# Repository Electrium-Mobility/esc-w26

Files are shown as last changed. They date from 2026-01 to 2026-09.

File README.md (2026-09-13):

# Electrium Mobility 2026 ESC
This repository contains all the firmware and hardware for Electrium Mobility's 2026 ESC, which is a 36V/15A 3-phase BLDC motor controller built around the STSPIN32G4 SiP's integrated gate driver and STM32G4 MCU, supporting 6-step and FOC commutation!

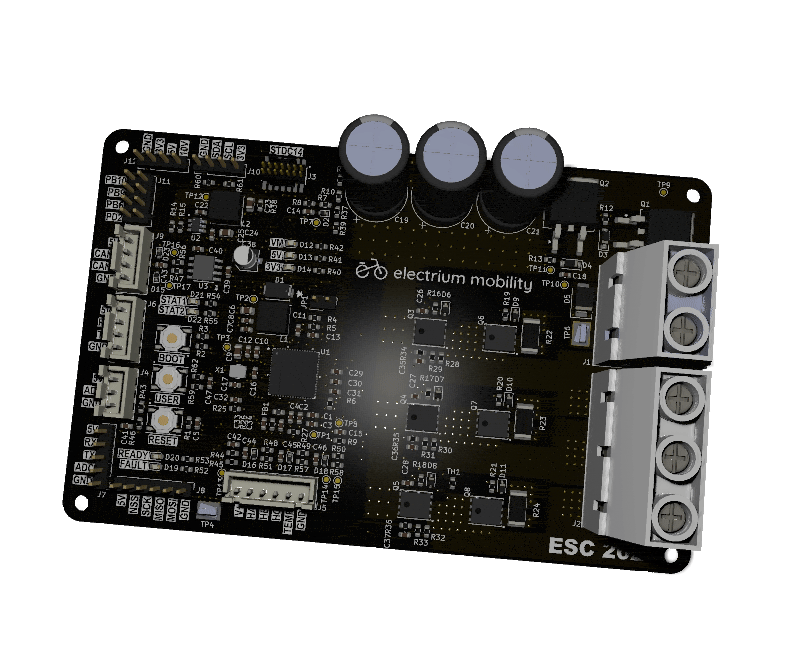
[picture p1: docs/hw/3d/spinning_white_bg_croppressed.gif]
 

## Architecture
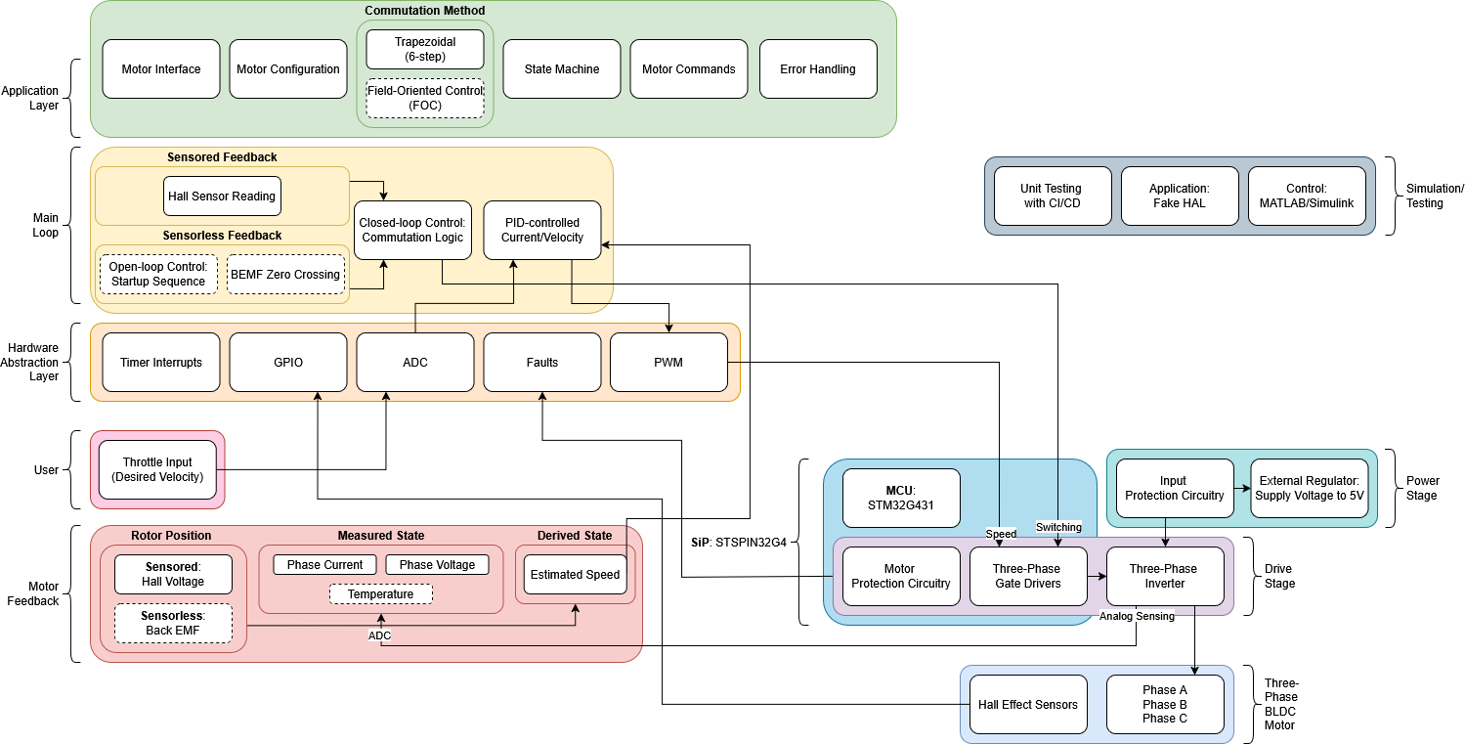
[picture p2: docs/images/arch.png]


## Features

### Power
- **Voltage**: 10-36V (maximum 10S battery pack)
- **Current**: 15A continuous (25A peak)
- **Power**: 500W (implied by above)
- External 5V/1A Buck Regulator
- Internal VCC (using 10V)/200mA Buck Regulator
- Internal 3.3V/150mA LDO
- 1410uF Bulk Capacitor Bank (bleed resistor discharges it in 1 min)

### Input Protection
- Reverse Polarity Protection (dual back-to-back PMOS)
- Inrush Current Limiting (RC soft-start)
- Transient Overvoltage Protection (60V TVS clamp)
- Short-circuit and Overcurrent Protection (SCREF divider)

### Sensing
- Phase Currents (0.5m shunt resistors) using Internal PGA with Overcurrent Protection (note: measures negative currents, but regenerative braking is not supported)
- Phase Voltages (for sensorless feedback method using BEMF zero-crossings)
- PCB Temperature (NTC thermistor)

### Interfaces
- Power Supply Input (VM+, VM-)
- SWD Programming/Debug (STDC14)
- **Throttle**: UART (digital commands), ADC (analog pot)
- **Motor**: Phase Outputs (U, V, W), Hall Sensors (A, B, C), Winding Temperature
- CAN (FD)
- Expansion Headers: SPI, I2C, 4 unused pins

### User I/O
- **Buttons**: RESET, BOOT, USER
- **LEDs**: Power Rails, READY, FAULT, 2 configurable (STATUS1, STATUS2)
- Onboard Test Points

### Board 
- 4-layer (stackup: Signal/Power, Ground, Ground, Signal)
- 125x80mm with 2oz Outer and 0.5oz Inner Copper
- Partitioned Grounding Scheme (separates high-power PGND and logic GND)

## Schematic
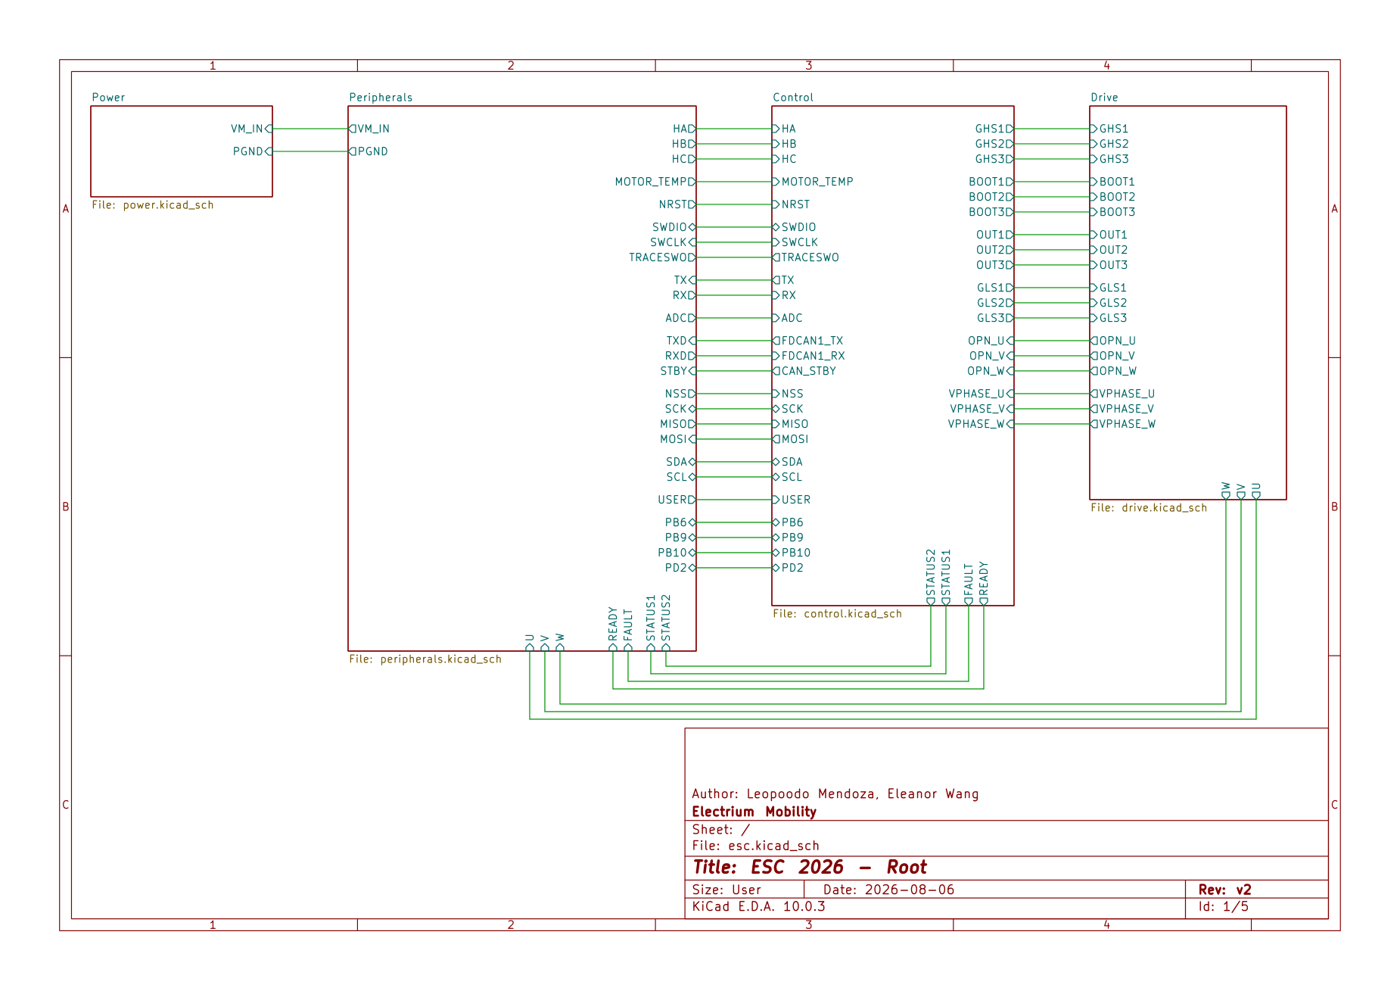
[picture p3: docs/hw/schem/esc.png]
 

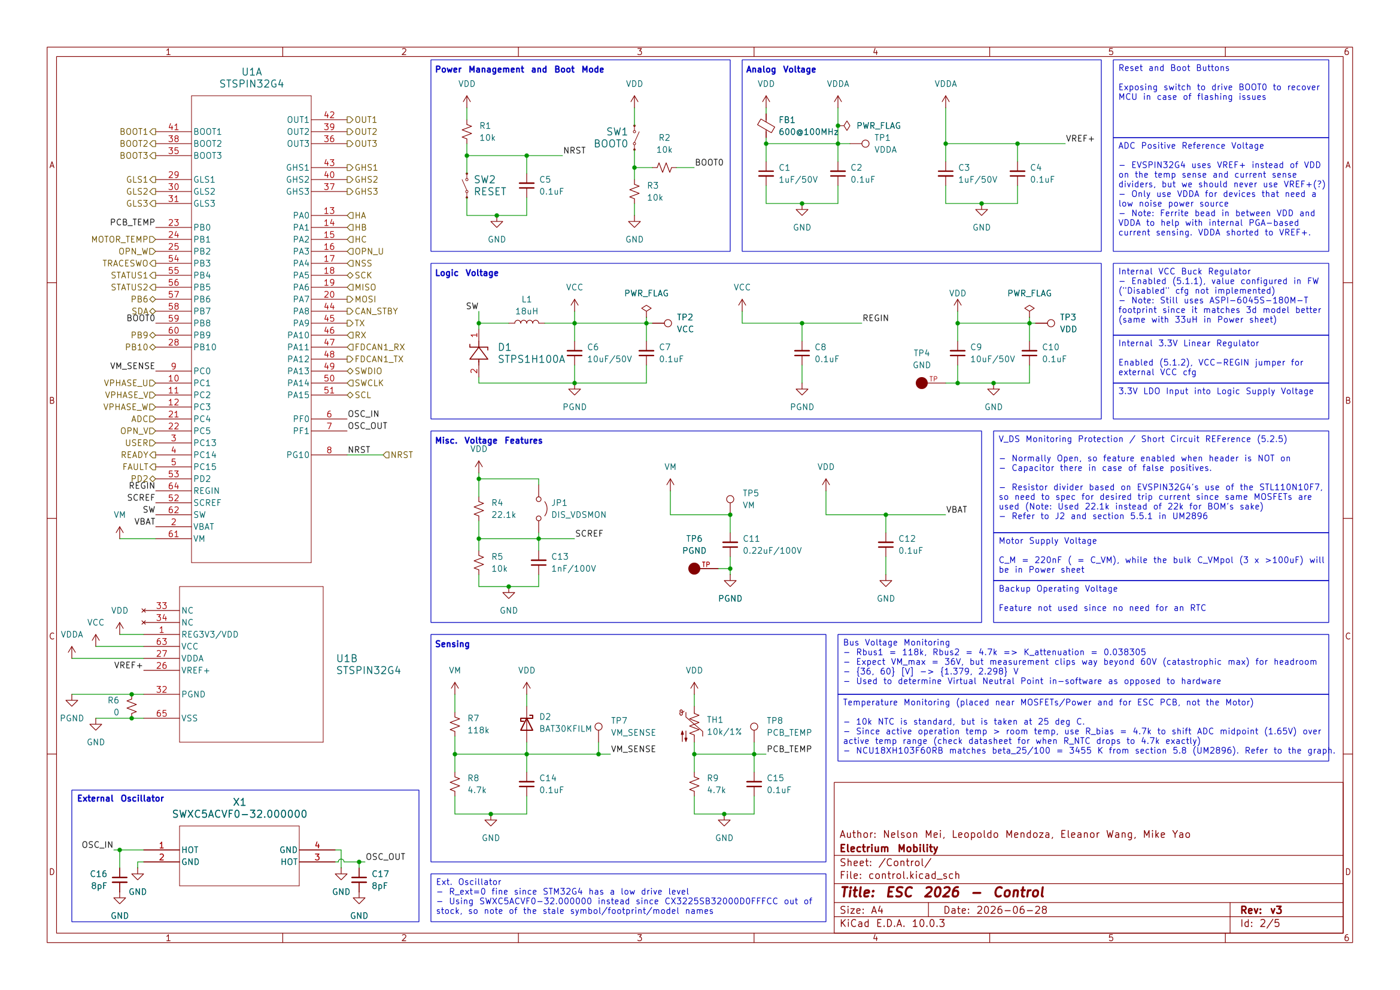
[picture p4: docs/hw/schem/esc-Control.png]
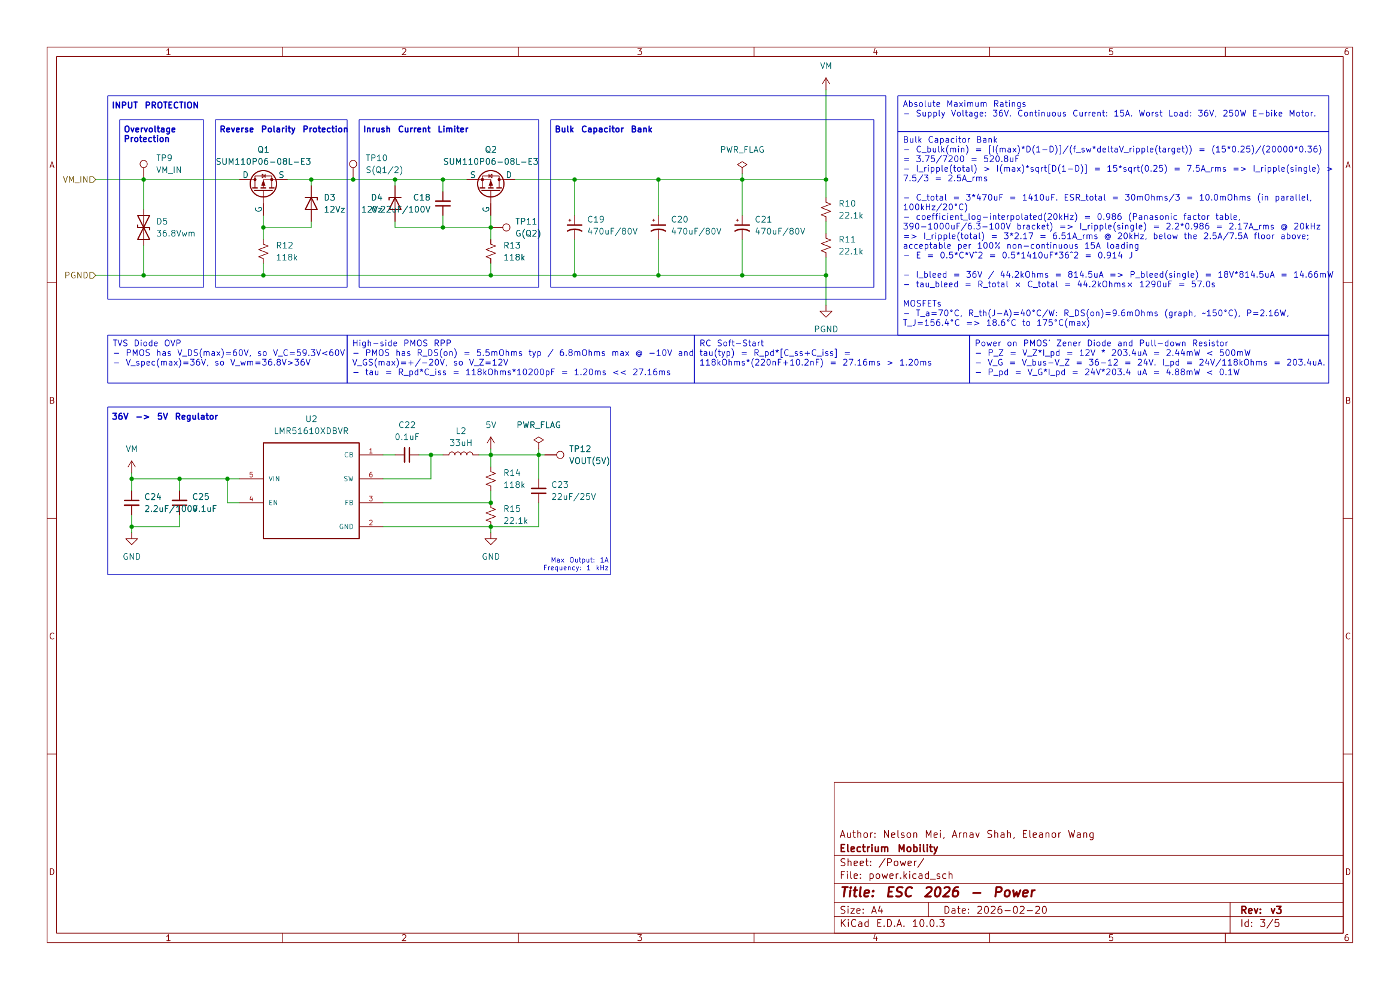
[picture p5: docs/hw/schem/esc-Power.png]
  
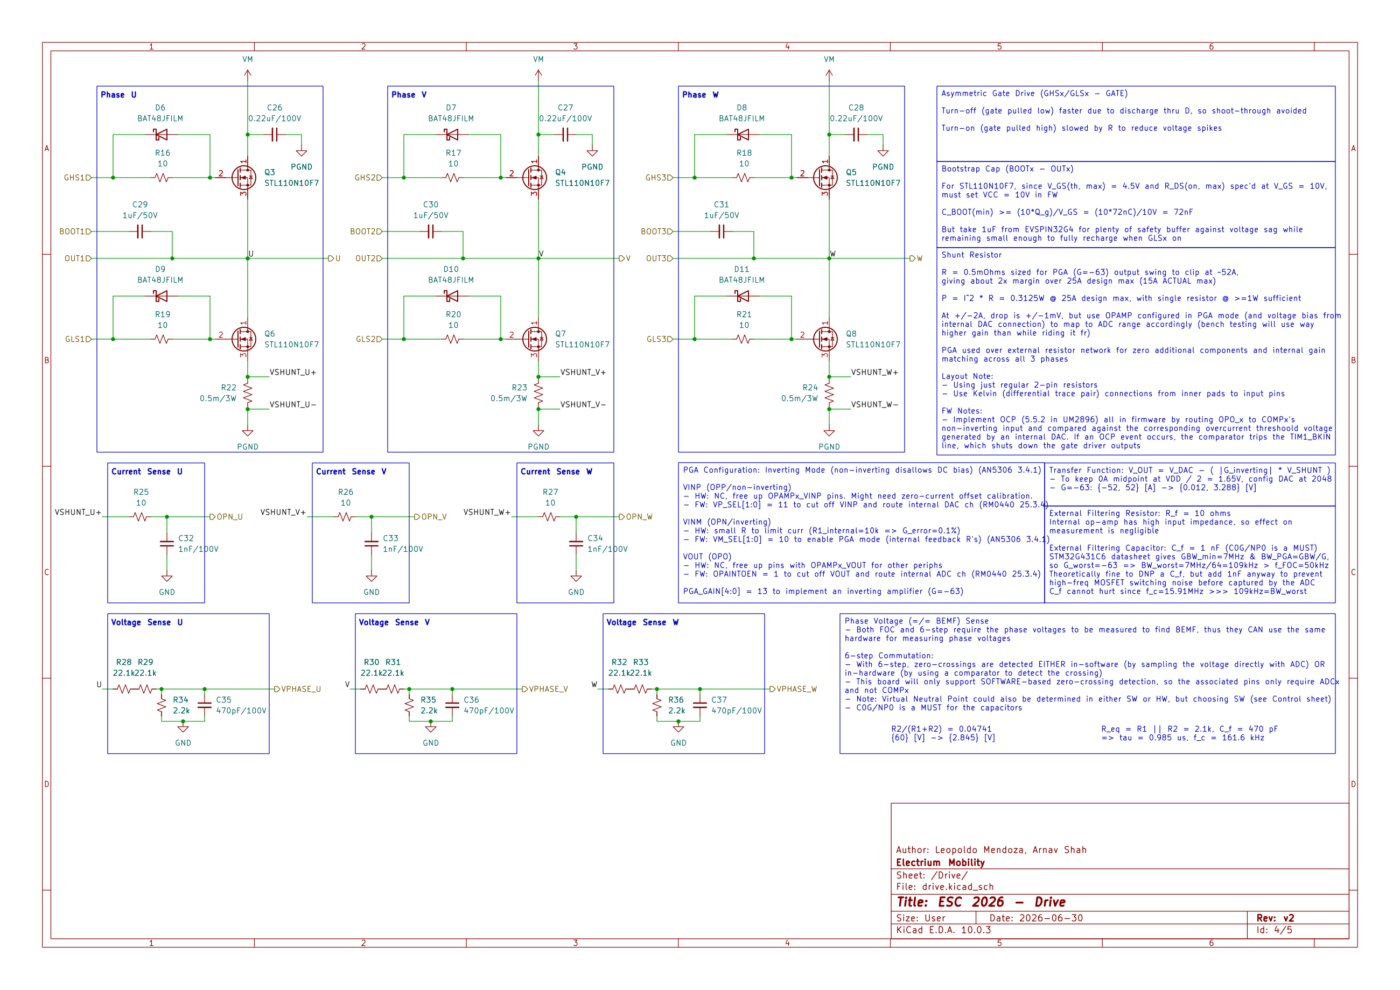
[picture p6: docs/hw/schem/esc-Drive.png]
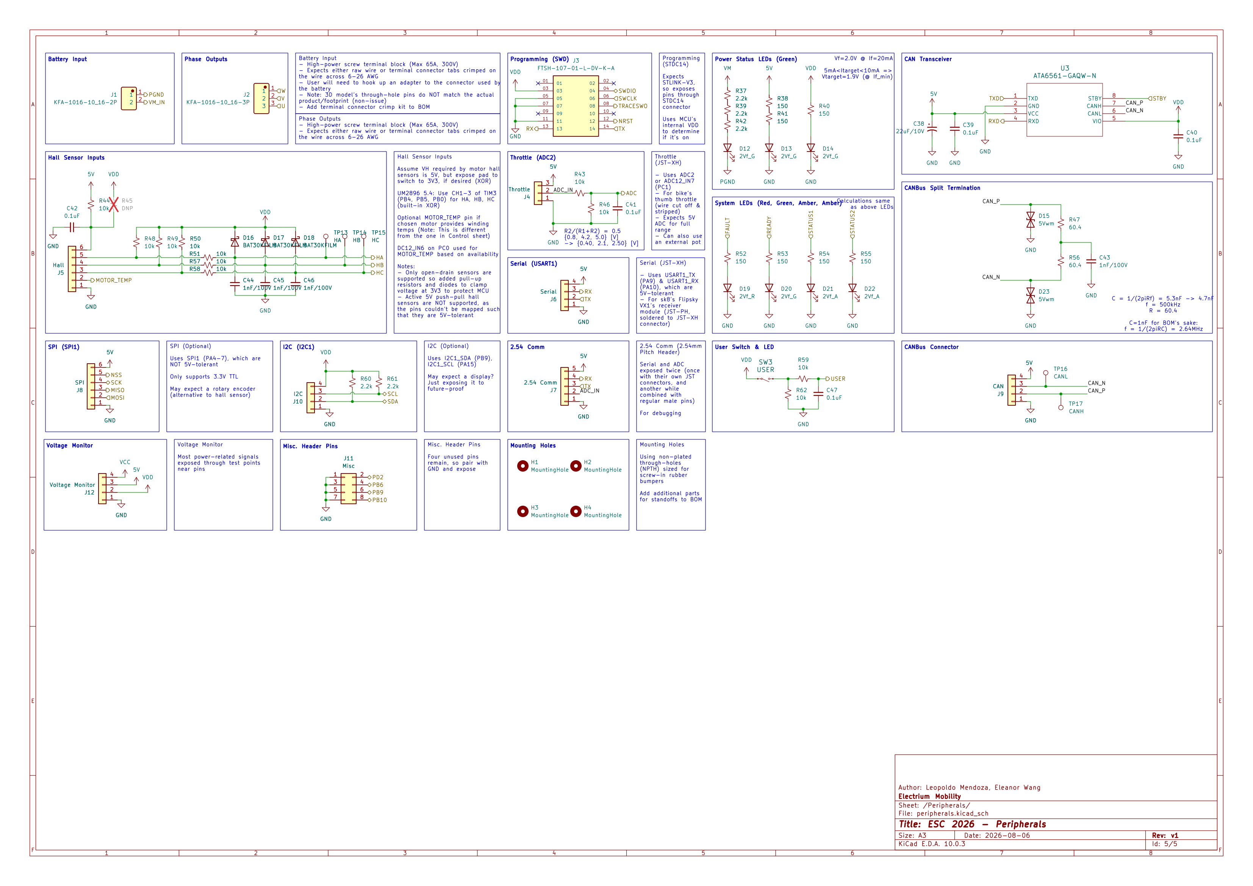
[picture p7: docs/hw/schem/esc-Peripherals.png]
  

## Routing

### Coloured (Traces Only, With Zones and Silkscreen)
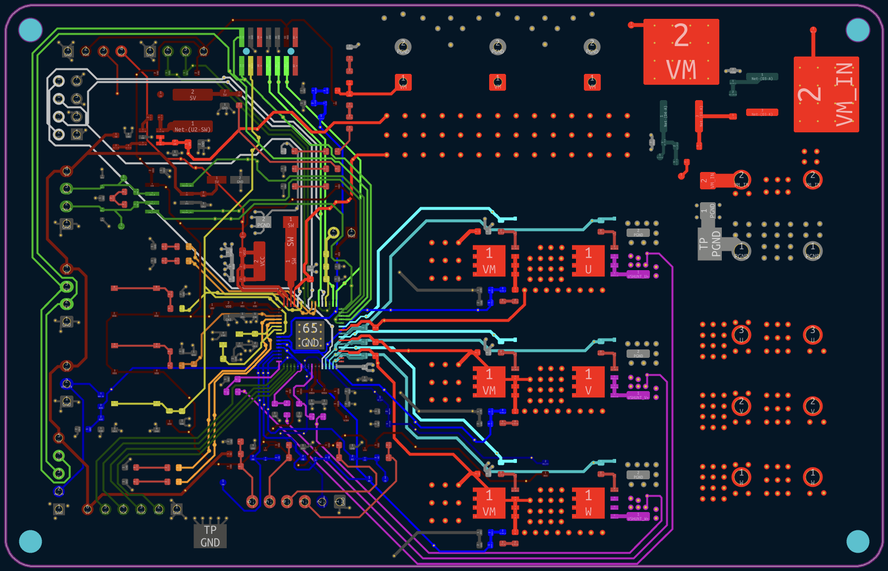
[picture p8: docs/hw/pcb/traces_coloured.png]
 
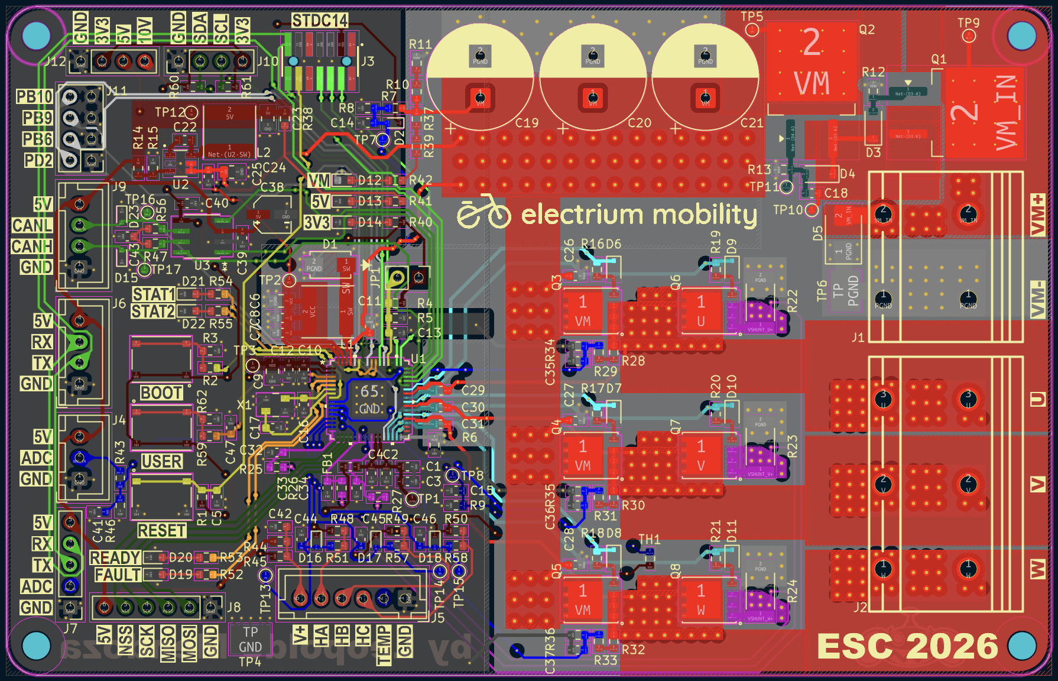
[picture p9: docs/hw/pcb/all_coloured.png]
 

### Colourless (Traces Only, With Zones and Silkscreen)
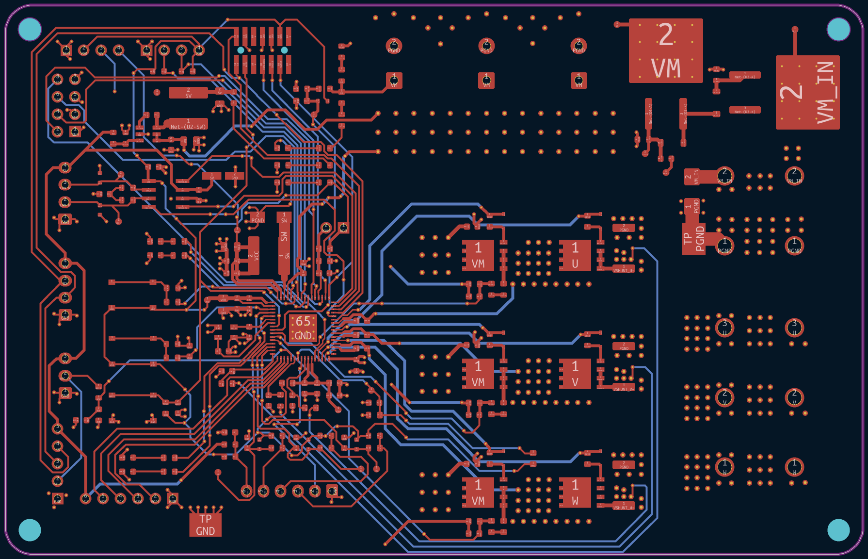
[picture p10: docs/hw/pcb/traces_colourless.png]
 
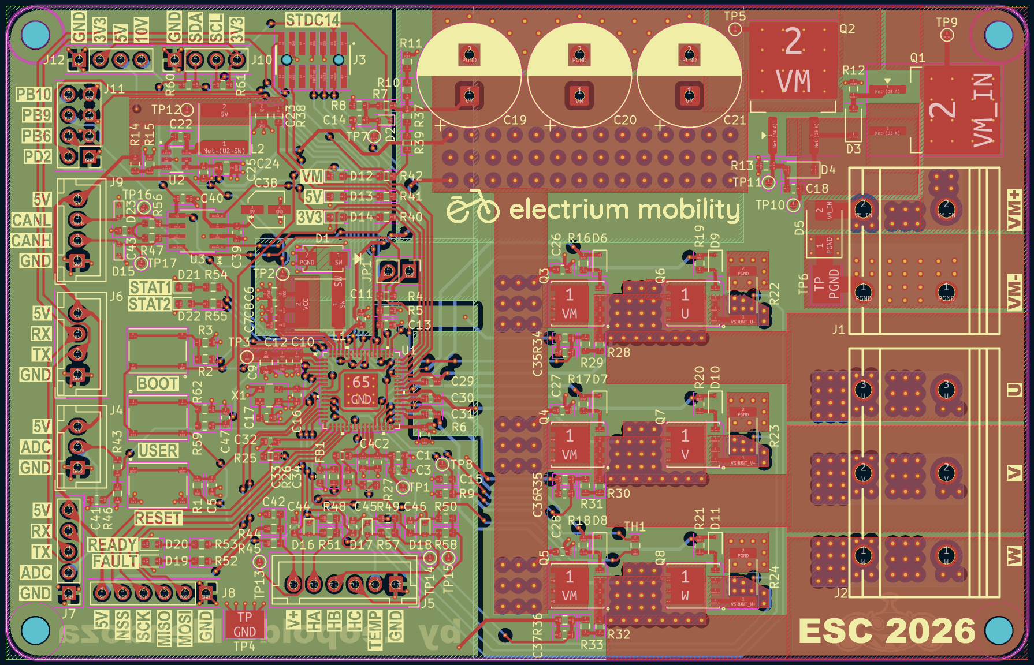
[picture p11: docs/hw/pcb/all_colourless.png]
 

## 3D Renders
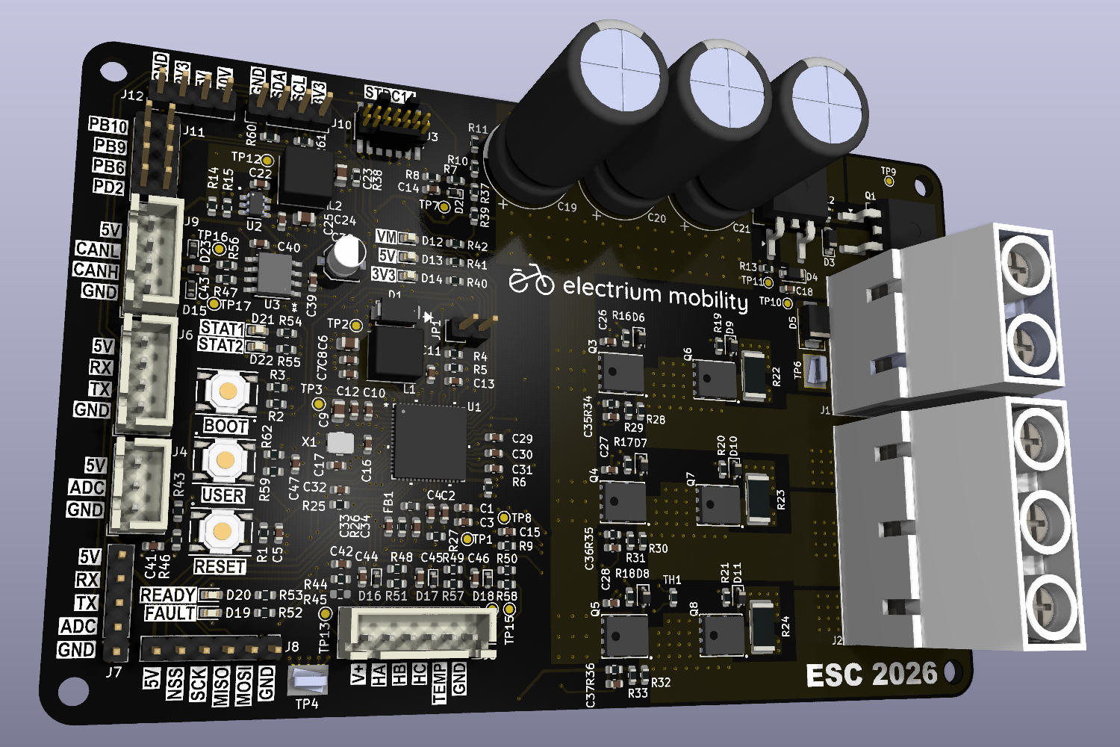
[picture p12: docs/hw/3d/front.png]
 
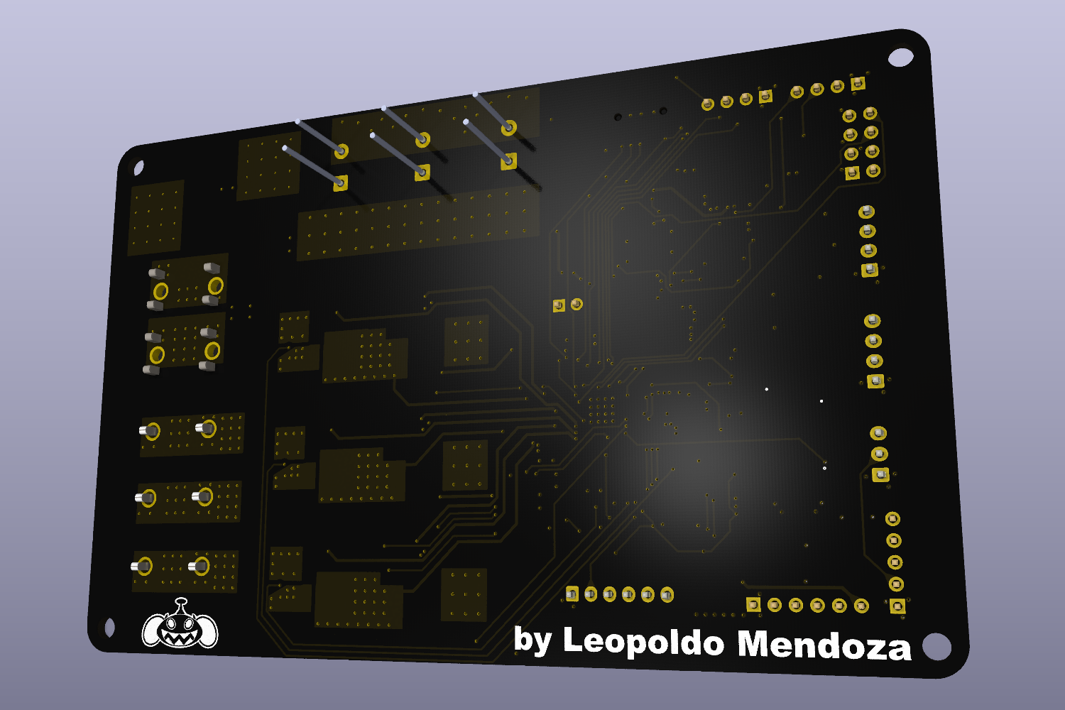
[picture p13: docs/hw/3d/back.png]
 

## Assembled Board
⚠️Under Construction⚠️

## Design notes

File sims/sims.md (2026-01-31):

This is where MATLAB and Simulink stuff will live.
For future reference, note that simulation (using close-to motor data) will happen on MATLAB/Simulink. 
This is in contrast to simple unit testing (not tryna model the system, but just if the application works as intended, with the the fake plaftorm functions subbed in for the real STM32 HAL functions), which will happen in the tests/ folder using the fake HAL implementations in platform/host/src/

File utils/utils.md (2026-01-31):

Math stuff like PID and filters will live here

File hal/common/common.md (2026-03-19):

This will contain the wrapper for the HAL called on by the application layer of the project!
Thus, depending on the target device (either a host PC or STM32 microcontroller), we configure the header files in /hal/common/inc/ to USE the corresponding implementation (in either /hal/host/src/ OR /hal/stm32/src/) under the hood.

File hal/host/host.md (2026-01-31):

This is where the "fake" implementation of the HAL wrapper functions will live. 
Before flashing the project onto an STM32 (and thus using the STM32 HAL under the hood of the HAL wrappers) to test with real hardware, we must simulate the HAL on a host PC.

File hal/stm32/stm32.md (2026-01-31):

All the junk (not actually, they're quite important auto-generated files) that the STM32CubeIDE will eventually go here (when we get there)

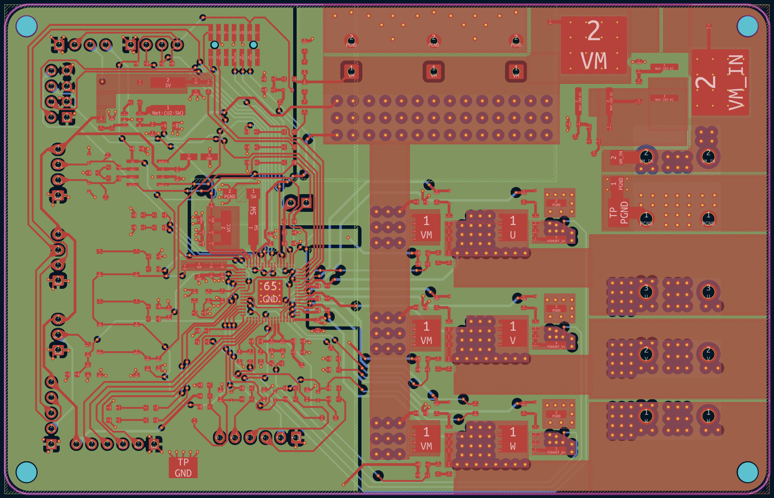
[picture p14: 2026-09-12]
docs/hw/pcb/traces_zones_colourless.png

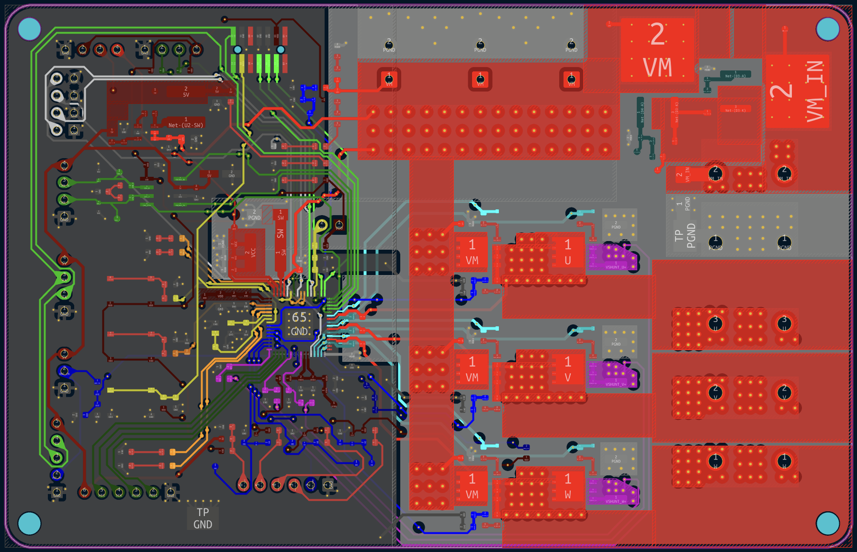
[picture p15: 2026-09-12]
docs/hw/pcb/traces_zones_coloured.png

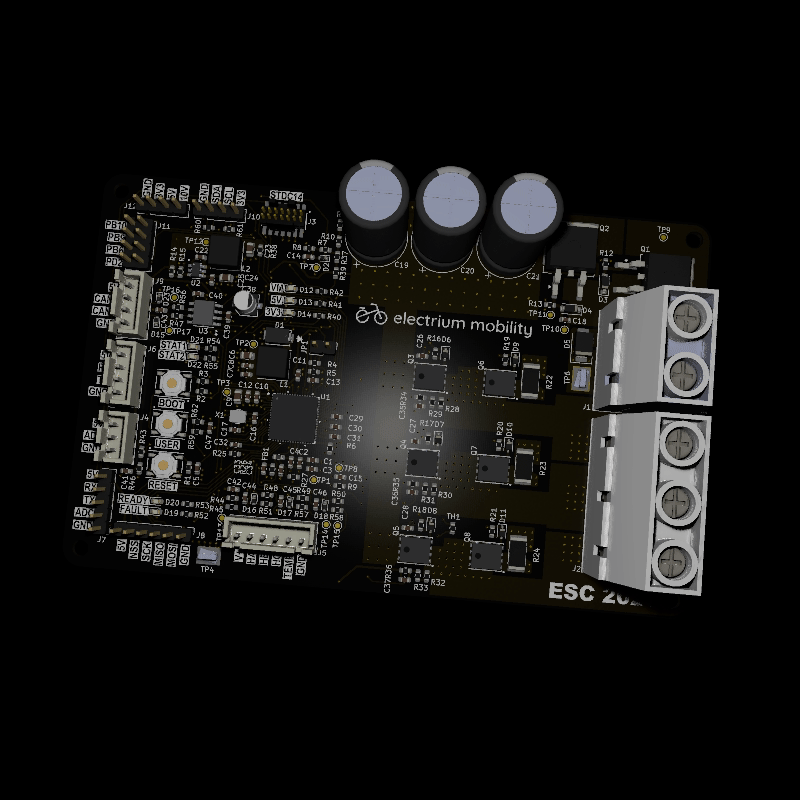
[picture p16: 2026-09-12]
docs/hw/3d/spinning_black_bg.gif

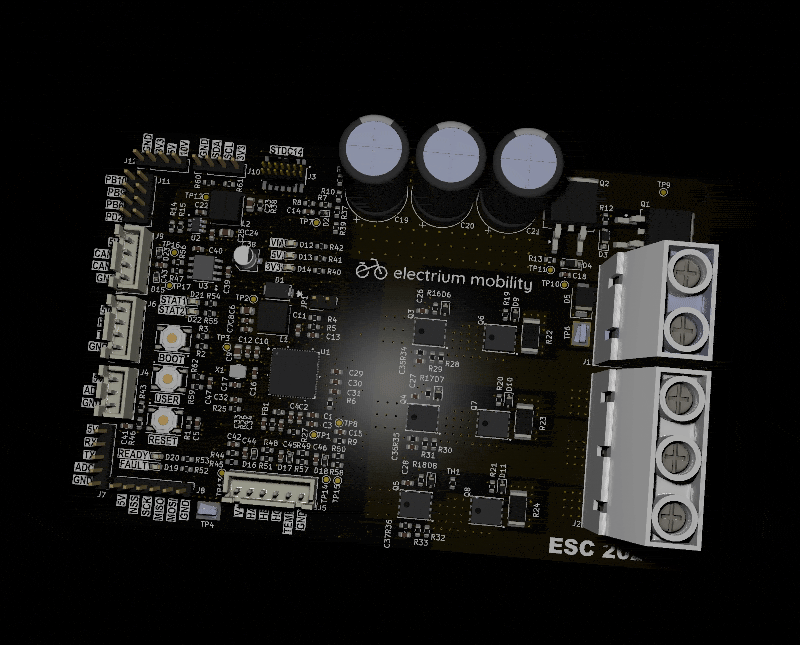
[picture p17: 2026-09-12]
docs/hw/3d/spinning_black_bg_croppressed.gif

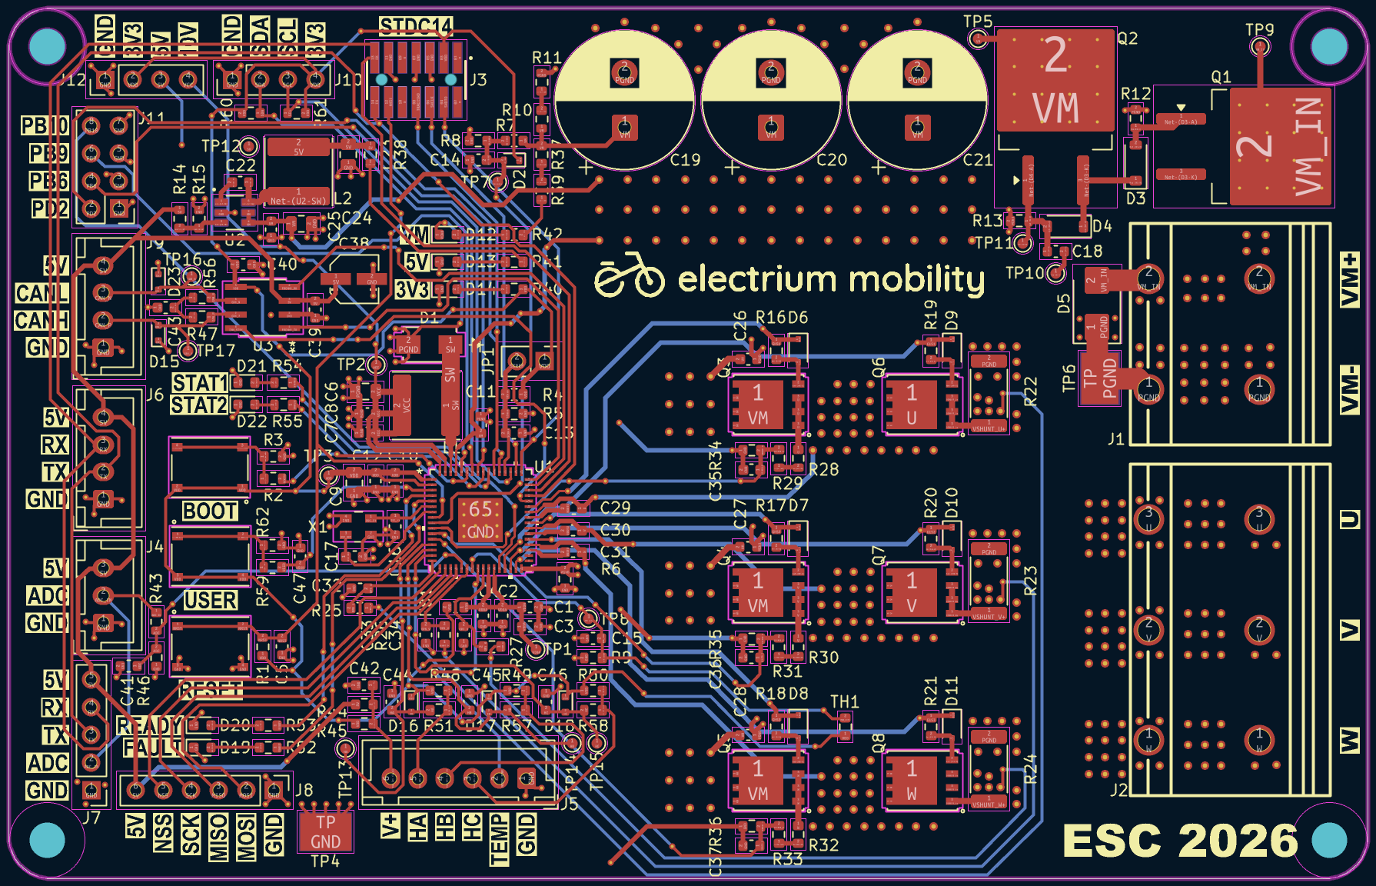
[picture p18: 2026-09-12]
docs/hw/pcb/traces_silk_colourless.png

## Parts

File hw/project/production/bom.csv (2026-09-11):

Designator | Footprint | Quantity | Value | LCSC Part #
C1, C29, C3, C30, C31 | 0603 | 5 | 1uF/50V | C15849
C10, C12, C14, C15, C2, C22, C25, C39, C4, C40, C41, C42, C47, C5, C7, C8 | 0603 | 16 | 0.1uF | C15725
C11, C18, C26, C27, C28 | 0603 | 5 | 0.22uF/100V | C2169715
C13, C32, C33, C34, C43, C44, C45, C46 | 0603 | 8 | 1nF/100V | C113793
C16, C17 | 0603 | 2 | 8pF | C519117
C19, C20, C21 | CP_Radial_D12.5mm_P5.00mm | 3 | 470uF/80V | C385881
C23 | 0805 | 1 | 22uF/25V | C45783
C24 | 0805 | 1 | 2.2uF/100V | C2981733
C35, C36, C37 | 0603 | 3 | 470pF/100V | C326973
C38 | EEEFKC220UAR | 1 | 22uF/10V | C401733
C6, C9 | 0805 | 2 | 10uF/50V | C440198
D1 | SMA_STM | 1 | STPS1H100A | C165701
D10, D11, D6, D7, D8, D9 | D_SOD-323 | 6 | BAT48JFILM | C2798199
D12, D13, D14, D20 | 0603 | 4 | 2Vf_G | C125098
D15, D23 | D_SOD-523 | 2 | 5Vwm | C51912417
D16, D17, D18, D2 | D_SOD-523 | 4 | BAT30KFILM | C2926449
D19 | 0603 | 1 | 2Vf_R | C94869
D21, D22 | 0603 | 2 | 2Vf_A | C5730905
D3, D4 | D_SOD-123 | 2 | 12Vz | C699126
D5 | D_SMB | 1 | 36.8Vwm | C468909
FB1 | 0603 | 1 | 600@100MHz | C304319
J1 | KFA-1016-10_16-2P | 1 | KFA-1016-10_16-2P | C475110
J10 | PinHeader_1x04_P2.54mm_Vertical | 1 | I2C | C3329732
J11 | PinHeader_2x04_P2.54mm_Vertical | 1 | Misc | C3333874
J12 | PinHeader_1x04_P2.54mm_Vertical | 1 | Voltage Monitor | C3329732
J2 | KFA-1016-10_16-3P | 1 | KFA-1016-10_16-3P | C475111
J3 | SAMTEC_FTSH-107-01-L-DV-K-A | 1 | FTSH-107-01-L-DV-K-A | C5563894
J4 | JST_XH_B3B-XH-A_1x03_P2.50mm_Vertical | 1 | Throttle | C144394
J5 | JST_XH_B6B-XH-A_1x06_P2.50mm_Vertical | 1 | Hall | C144397
J6 | JST_XH_B4B-XH-A_1x04_P2.50mm_Vertical | 1 | Serial | C144395
J7 | PinHeader_1x05_P2.54mm_Vertical | 1 | 2.54 Comm | C3347212
J8 | PinHeader_1x06_P2.54mm_Vertical | 1 | SPI | C5427040
J9 | JST_XH_B4B-XH-A_1x04_P2.50mm_Vertical | 1 | CAN | C144395
JP1 | PinHeader_1x02_P2.54mm_Vertical | 1 | DIS_VDSMON | C5426960
L1 | L_Sunlord_SWPA6045S | 1 | 18uH | C96954
L2 | L_Sunlord_SWPA6045S | 1 | 33uH | C83451
Q1, Q2 | TO-263-2 | 2 | SUM110P06-08L-E3 | C5364638
Q3, Q4, Q5, Q6, Q7, Q8 | MOSFET_10N10F7_STM | 6 | STL110N10F7 | C672185
R1, R2, R3, R43, R44, R46, R48, R49, R5, R50, R51, R57, R58, R59, R62 | 0603 | 15 | 10k | C25804
R10, R11, R15, R28, R29, R30, R31, R32, R33, R4 | 0603 | 10 | 22.1k | C25961
R12, R13, R14, R7 | 0603 | 4 | 118k | C25806
R16, R17, R18, R19, R20, R21, R25, R26, R27 | 0603 | 9 | 10 | C22859
R22, R23, R24 | 2512 | 3 | 0.5m/3W | C53447178
R34, R35, R36, R37, R39, R42, R60, R61 | 0603 | 8 | 2.2k | C4190
R38, R40, R41, R52, R53, R54, R55 | 0603 | 7 | 150 | C22808
R47, R56 | 0603 | 2 | 60.4 | C23090
R6 | 0603 | 1 | 0 | C21189
R8, R9 | 0603 | 2 | 4.7k | C23162
SW1 | TS-1187A-B-A-B | 1 | BOOT0 | C318884
SW2 | TS-1187A-B-A-B | 1 | RESET | C318884
SW3 | TS-1187A-B-A-B | 1 | USER | C318884
TH1 | 0603 | 1 | 10k/1% | C440252
TP4 | KEYSTONE_5016 | 1 | GND | C238129
TP6 | KEYSTONE_5016 | 1 | PGND | C238129
U1 | QFN_IN32G4_STM | 1 | STSPIN32G4 | C7434864
U2 | LMR51610XDBVR-SOT95P280X145-6N | 1 | LMR51610XDBVR | C20539658
U3 | SOIC8_4P9X3P9MC_MCH | 1 | ATA6561-GAQW-N | C616016
X1 | xtal4_CX3225SB_AVX | 1 | SWXC5ACVF0-32.000000 | C22399832

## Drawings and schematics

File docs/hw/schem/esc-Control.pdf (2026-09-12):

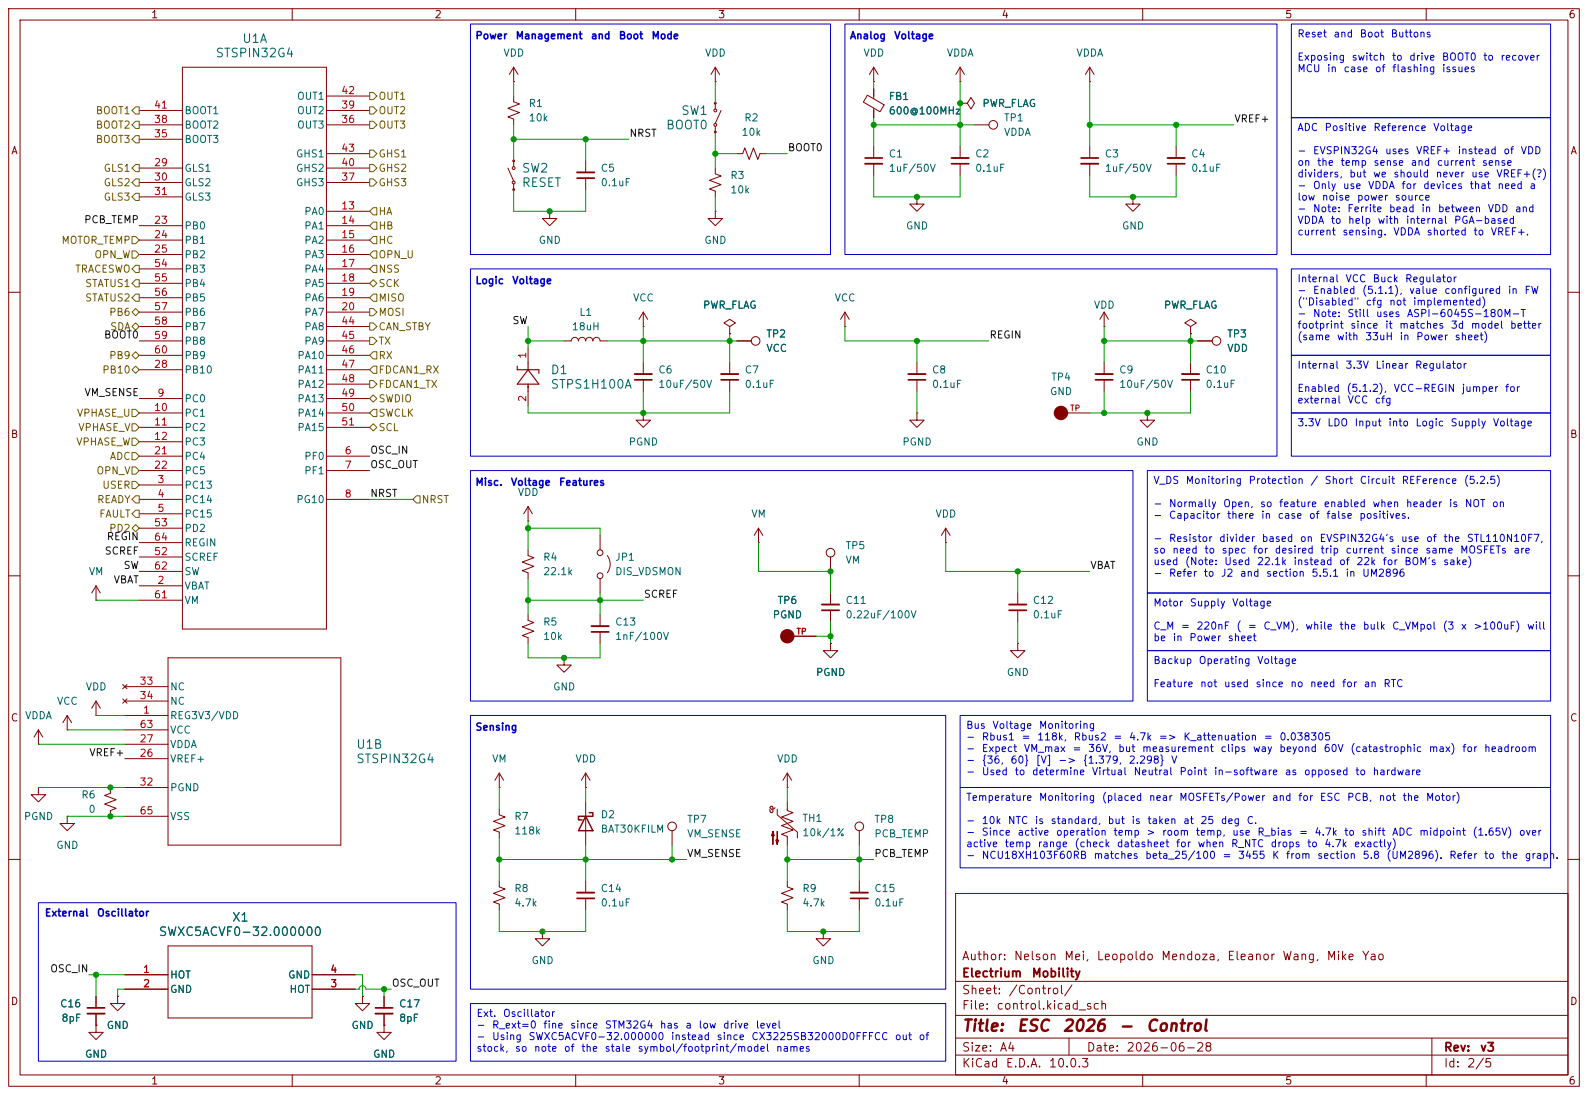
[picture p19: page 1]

Power Management and Boot Mode Misc. Voltage Features

Reset and Boot Buttons Exposing switch to drive BOOT0 to recover MCU in case of flashing issues ADC Positive Reference Voltage - EVSPIN32G4 uses VREF+ instead of VDD

on the temp sense and current sense dividers, but we should never use VREF+(?) - Only use VDDA for devices that need a

low noise power source - Note: Ferrite bead in between VDD and

VDDA to help with internal PGA-based
current sensing. VDDA shorted to VREF+.

Internal VCC Buck Regulator - Enabled (5.1.1), value configured in FW

("Disabled" cfg not implemented) - Note: Still uses ASPI-6045S-180M-T

footprint since it matches 3d model better (same with 33uH in Power sheet)

Internal 3.3V Linear Regulator Enabled (5.1.2), VCC-REGIN jumper for external VCC cfg

3.3V LDO Input into Logic Supply Voltage Ext. Oscillator - R_ext=0 fine since STM32G4 has a low drive level - Using SWXC5ACVF0-32.000000 instead since CX3225SB32000D0FFFCC out of stock, so note of the stale symbol/footprint/model names

V_DS Monitoring Protection / Short Circuit REFerence (5.2.5) - Normally Open, so feature enabled when header is NOT on - Capacitor there in case of false positives. - Resistor divider based on EVSPIN32G4's use of the STL110N10F7, so need to spec for desired trip current since same MOSFETs are used (Note: Used 22.1k instead of 22k for BOM's sake) - Refer to J2 and section 5.5.1 in UM2896

Temperature Monitoring (placed near MOSFETs/Power and for ESC PCB, not the Motor) - 10k NTC is standard, but is taken at 25 deg C. - Since active operation temp > room temp, use R_bias = 4.7k to shift ADC midpoint (1.65V) over active temp range (check datasheet for when R_NTC drops to 4.7k exactly) - NCU18XH103F60RB matches beta_25/100 = 3455 K from section 5.8 (UM2896). Refer to the graph. Motor Supply Voltage C_M = 220nF ( = C_VM), while the bulk C_VMpol (3 x >100uF) will be in Power sheet Bus Voltage Monitoring - Rbus1 = 118k, Rbus2 = 4.7k => K_attenuation = 0.038305 - Expect VM_max = 36V, but measurement clips way beyond 60V (catastrophic max) for headroom

Feature not used since no need for an RTC

- {36, 60} [V] -> {1.379, 2.298} V - Used to determine Virtual Neutral Point in-software as opposed to hardware

Author: Nelson Mei, Leopoldo Mendoza, Eleanor Wang, Mike Yao
Electrium Mobility
Sheet: /Control/
File: control.kicad_sch
Title: ESC 2026 - Control

Size: A4 | Rev: v3
KiCad E.D.A. 10.0.3 | Id: 2/5

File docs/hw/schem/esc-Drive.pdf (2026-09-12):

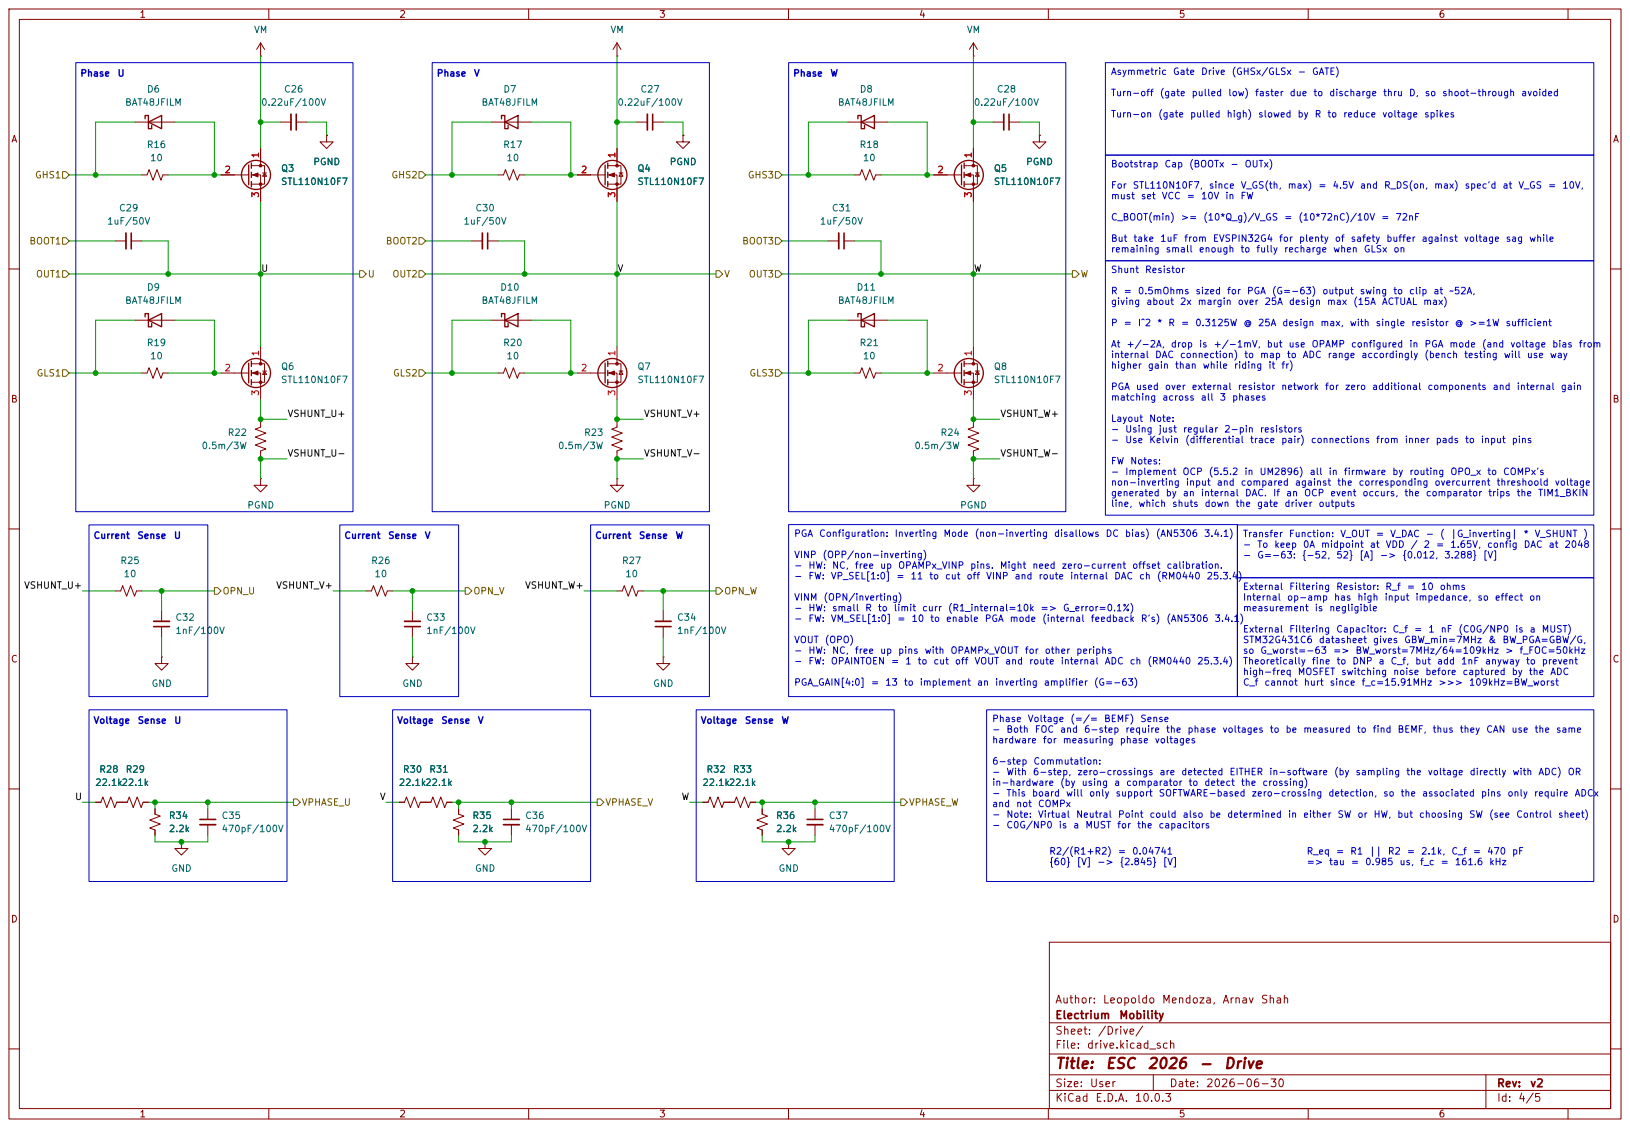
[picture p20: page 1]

Asymmetric Gate Drive (GHSx/GLSx - GATE) Turn-off (gate pulled low) faster due to discharge thru D, so shoot-through avoided

Turn-on (gate pulled high) slowed by R to reduce voltage spikes

Bootstrap Cap (BOOTx - OUTx) For STL110N10F7, since V_GS(th, max) = 4.5V and R_DS(on, max) spec'd at V_GS = 10V, must set VCC = 10V in FW

C_BOOT(min) >= (10*Q_g)/V_GS = (10*72nC)/10V = 72nF But take 1uF from EVSPIN32G4 for plenty of safety buffer against voltage sag while

remaining small enough to fully recharge when GLSx on
C_f cannot hurt since f_c=15.91MHz >>> 109kHz=BW_worst Shunt Resistor R = 0.5mOhms sized for PGA (G=-63) output swing to clip at ~52A,

giving about 2x margin over 25A design max (15A ACTUAL max) P = I^2 * R = 0.3125W @ 25A design max, with single resistor @ >=1W sufficient At +/-2A, drop is +/-1mV, but use OPAMP configured in PGA mode (and voltage bias from

internal DAC connection) to map to ADC range accordingly (bench testing will use way higher gain than while riding it fr) PGA used over external resistor network for zero additional components and internal gain

matching across all 3 phases

Layout Note: - Using just regular 2-pin resistors - Use Kelvin (differential trace pair) connections from inner pads to input pins FW Notes: - Implement OCP (5.5.2 in UM2896) all in firmware by routing OPO_x to COMPx's non-inverting input and compared against the corresponding overcurrent threshoold voltage

generated by an internal DAC. If an OCP event occurs, the comparator trips the TIM1_BKIN
line, which shuts down the gate driver outputs

Transfer Function: V_OUT = V_DAC - ( |G_inverting| * V_SHUNT ) - To keep 0A midpoint at VDD / 2 = 1.65V, config DAC at 2048 - G=-63: {-52, 52} [A] -> {0.012, 3.288} [V] PGA Configuration: Inverting Mode (non-inverting disallows DC bias) (AN5306 3.4.1) VINP (OPP/non-inverting) - HW: NC, free up OPAMPx_VINP pins. Might need zero-current offset calibration. - FW: VP_SEL[1:0] = 11 to cut off VINP and route internal DAC ch (RM0440 25.3.4) VINM (OPN/inverting) - HW: small R to limit curr (R1_internal=10k => G_error=0.1%) - FW: VM_SEL[1:0] = 10 to enable PGA mode (internal feedback R's) (AN5306 3.4.1) VOUT (OPO) - HW: NC, free up pins with OPAMPx_VOUT for other periphs - FW: OPAINTOEN = 1 to cut off VOUT and route internal ADC ch (RM0440 25.3.4)

External Filtering Resistor: R_f = 10 ohms
Internal op-amp has high input impedance, so effect on measurement is negligible External Filtering Capacitor: C_f = 1 nF (C0G/NP0 is a MUST) STM32G431C6 datasheet gives GBW_min=7MHz & BW_PGA=GBW/G, so G_worst=-63 => BW_worst=7MHz/64=109kHz > f_FOC=50kHz

Theoretically fine to DNP a C_f, but add 1nF anyway to prevent
high-freq MOSFET switching noise before captured by the ADC

PGA_GAIN[4:0] = 13 to implement an inverting amplifier (G=-63) Phase Voltage (=/= BEMF) Sense - Both FOC and 6-step require the phase voltages to be measured to find BEMF, thus they CAN use the same hardware for measuring phase voltages

6-step Commutation: - With 6-step, zero-crossings are detected EITHER in-software (by sampling the voltage directly with ADC) OR

R_eq = R1 || R2 = 2.1k, C_f = 470 pF => tau = 0.985 us, f_c = 161.6 kHz R29

in-hardware (by using a comparator to detect the crossing) - This board will only support SOFTWARE-based zero-crossing detection, so the associated pins only require ADCx and not COMPx - Note: Virtual Neutral Point could also be determined in either SW or HW, but choosing SW (see Control sheet) - C0G/NP0 is a MUST for the capacitors

Author: Leopoldo Mendoza, Arnav Shah
Electrium Mobility
Sheet: /Drive/
File: drive.kicad_sch
Title: ESC 2026 - Drive

Size: User | Rev: v2
KiCad E.D.A. 10.0.3 | Id: 4/5

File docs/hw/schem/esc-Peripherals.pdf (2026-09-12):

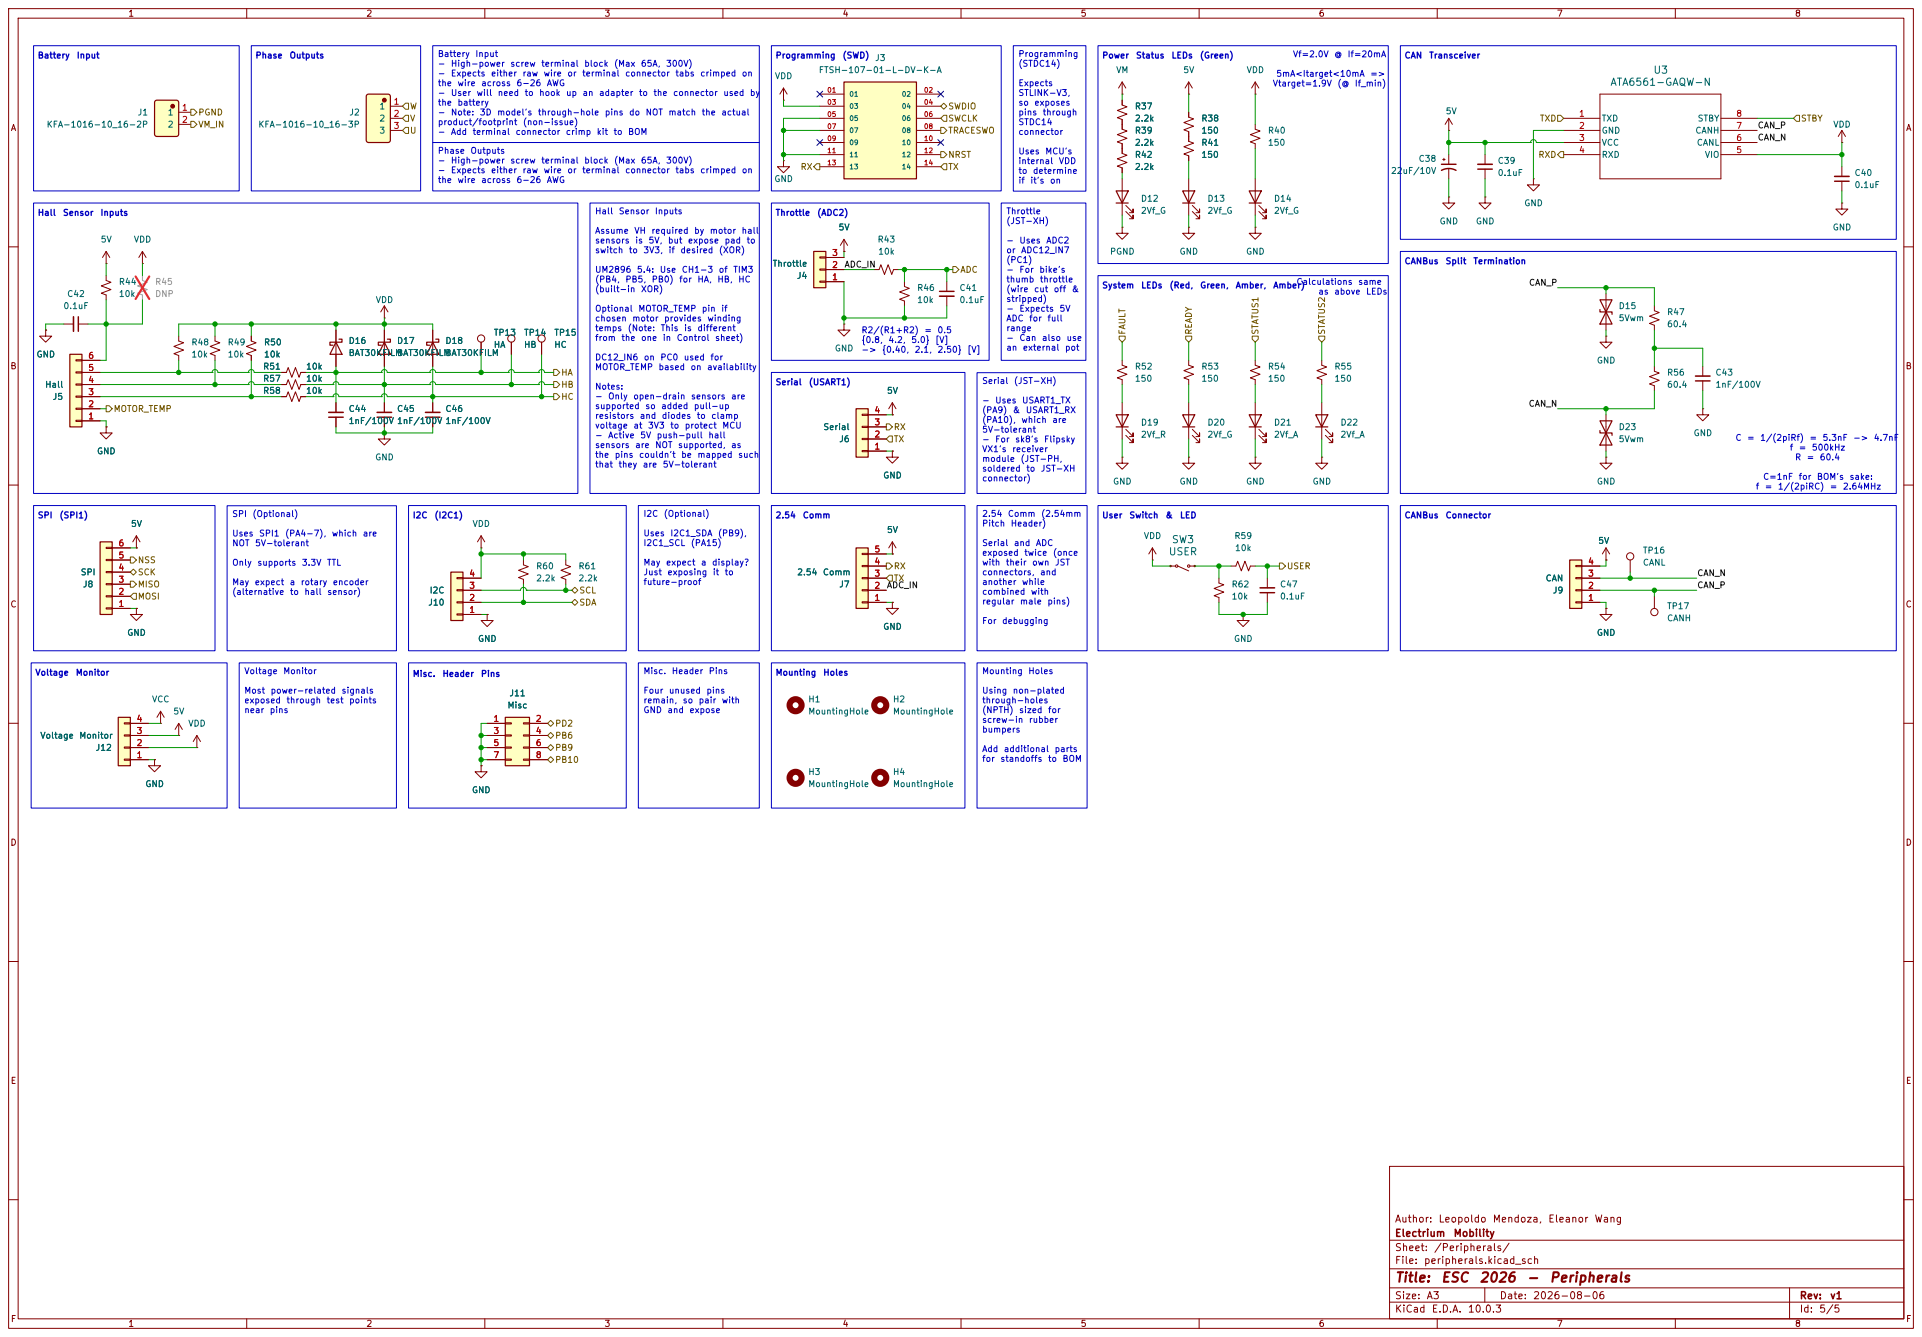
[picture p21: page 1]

Phase Outputs Hall Sensor Inputs

that they are 5V-tolerant Battery Input - High-power screw terminal block (Max 65A, 300V) - Expects either raw wire or terminal connector tabs crimped on

Vtarget=1.9V (@ If_min) Calculations same as above LEDs User Switch & LED

the wire across 6-26 AWG - User will need to hook up an adapter to the connector used by

Expects
STLINK-V3, so exposes pins through STDC14

the battery - Note: 3D model's through-hole pins do NOT match the actual product/footprint (non-issue) - Add terminal connector crimp kit to BOM

if it's on Serial (JST-XH) - Uses USART1_TX

Phase Outputs - High-power screw terminal block (Max 65A, 300V) - Expects either raw wire or terminal connector tabs crimped on

Hall Sensor Inputs Assume VH required by motor hall sensors is 5V, but expose pad to

switch to 3V3, if desired (XOR) UM2896 5.4: Use CH1-3 of TIM3

(PB4, PB5, PB0) for HA, HB, HC
(built-in XOR)

Optional MOTOR_TEMP pin if chosen motor provides winding

ADC for full range - Can also use an external pot

temps (Note: This is different
from the one in Control sheet) DC12_IN6 on PC0 used for MOTOR_TEMP based on availability Notes: - Only open-drain sensors are

supported so added pull-up
resistors and diodes to clamp
voltage at 3V3 to protect MCU - Active 5V push-pull hall sensors are NOT supported, as

(PA9) & USART1_RX
(PA10), which are 5V-tolerant - For sk8's Flipsky VX1's receiver module (JST-PH, soldered to JST-XH

the pins couldn't be mapped such

exposed through test points near pins SPI (Optional) Uses SPI1 (PA4-7), which are NOT 5V-tolerant Only supports 3.3V TTL May expect a rotary encoder (alternative to hall sensor)

Pitch Header) Serial and ADC

May expect a display?
Just exposing it to
future-proof

exposed twice (once with their own JST connectors, and

another while
combined with
regular male pins) For debugging

Voltage Monitor Most power-related signals

Mounting Holes Using non-plated

remain, so pair with GND and expose

through-holes
(NPTH) sized for screw-in rubber bumpers Add additional parts

for standoffs to BOM

Author: Leopoldo Mendoza, Eleanor Wang
Electrium Mobility
Sheet: /Peripherals/
File: peripherals.kicad_sch
Title: ESC 2026 - Peripherals

Size: A3 | Rev: v1
KiCad E.D.A. 10.0.3 | Id: 5/5 | F Date: 2026-08-06

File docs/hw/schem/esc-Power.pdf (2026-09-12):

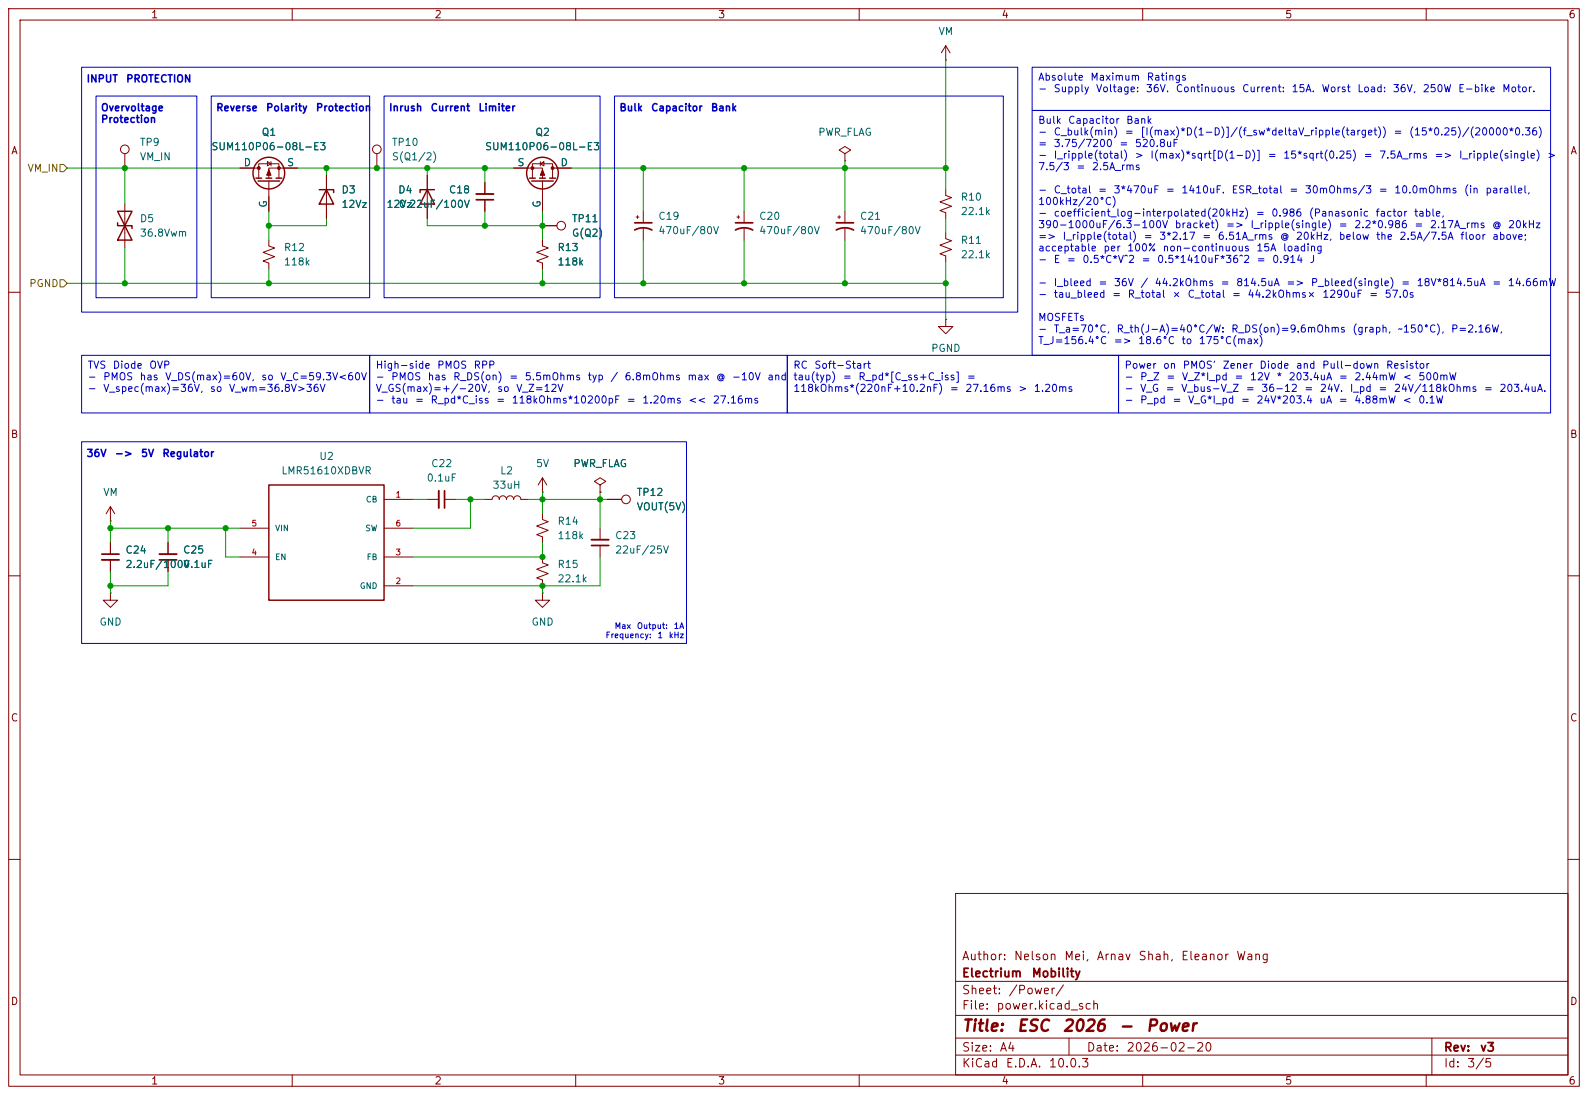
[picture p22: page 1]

Absolute Maximum Ratings - Supply Voltage: 36V. Continuous Current: 15A. Worst Load: 36V, 250W E-bike Motor. Power on PMOS' Zener Diode and Pull-down Resistor - P_Z = V_Z*I_pd = 12V * 203.4uA = 2.44mW < 500mW - V_G = V_bus−V_Z = 36−12 = 24V. I_pd = 24V/118kOhms = 203.4uA. - P_pd = V_G*I_pd = 24V*203.4 uA = 4.88mW < 0.1W

100kHz/20°C) - coefficient_log-interpolated(20kHz) = 0.986 (Panasonic factor table,

390-1000uF/6.3-100V bracket) => I_ripple(single) = 2.2*0.986 = 2.17A_rms @ 20kHz => I_ripple(total) = 3*2.17 = 6.51A_rms @ 20kHz, below the 2.5A/7.5A floor above;

acceptable per 100% non-continuous 15A loading - E = 0.5*C*V^2 = 0.5*1410uF*36^2 = 0.914 J - I_bleed = 36V / 44.2kOhms = 814.5uA => P_bleed(single) = 18V*814.5uA = 14.66mW - tau_bleed = R_total × C_total = 44.2kOhms× 1290uF = 57.0s MOSFETs - T_a=70°C, R_th(J-A)=40°C/W: R_DS(on)=9.6mOhms (graph, ~150°C), P=2.16W,

Author: Nelson Mei, Arnav Shah, Eleanor Wang
Electrium Mobility
Sheet: /Power/
File: power.kicad_sch
Title: ESC 2026 - Power

Size: A4 | Rev: v3
KiCad E.D.A. 10.0.3 | Id: 3/5

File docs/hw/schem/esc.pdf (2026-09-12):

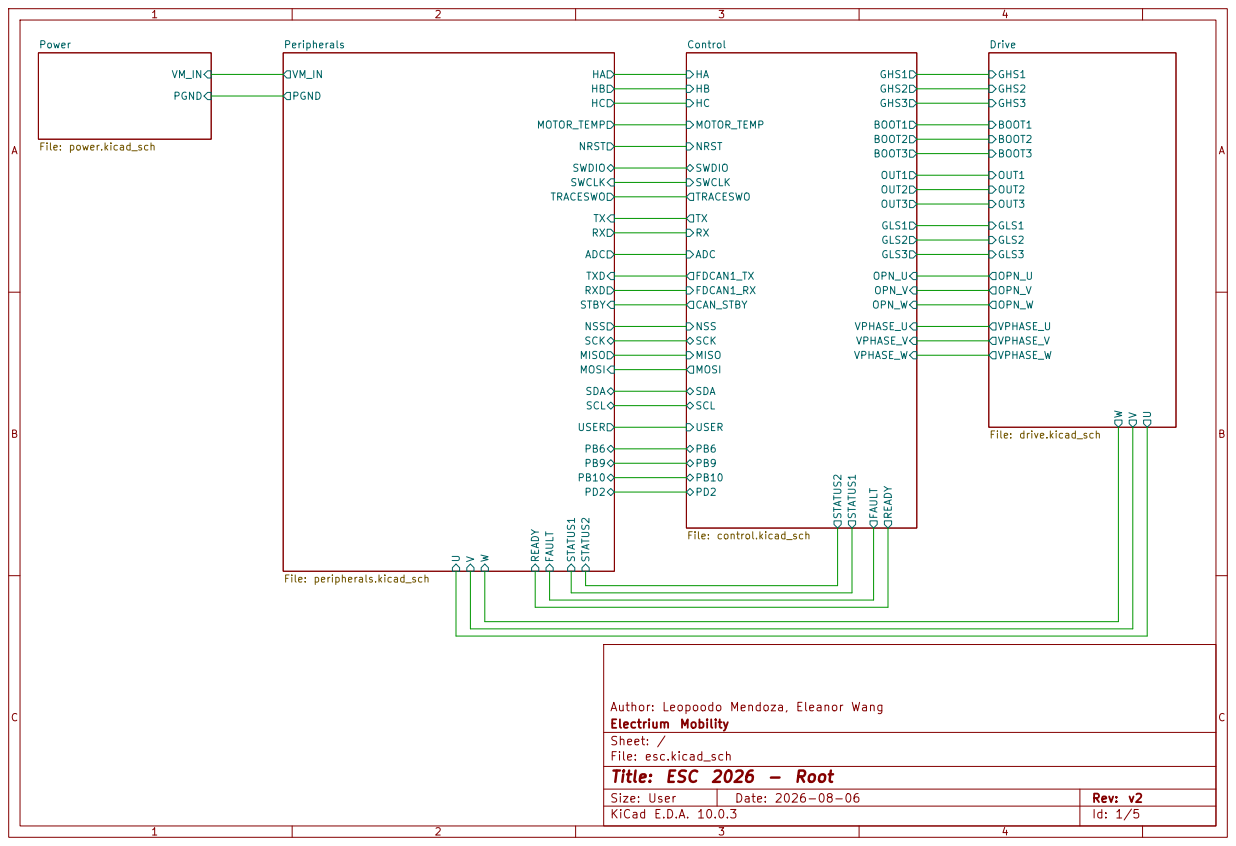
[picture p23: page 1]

VPHASE_W STATUS2 STATUS1 PB9 PD2 PB10 Control File: control.kicad_sch NRST SWCLK

TXRX
ADC MOSI SCK NSS MISO

Author: Leopoodo Mendoza, Eleanor Wang
Electrium Mobility
Sheet: /
File: esc.kicad_sch
Title: ESC 2026 - Root

Size: User | Rev: v2
KiCad E.D.A. 10.0.3 | Id: 1/5

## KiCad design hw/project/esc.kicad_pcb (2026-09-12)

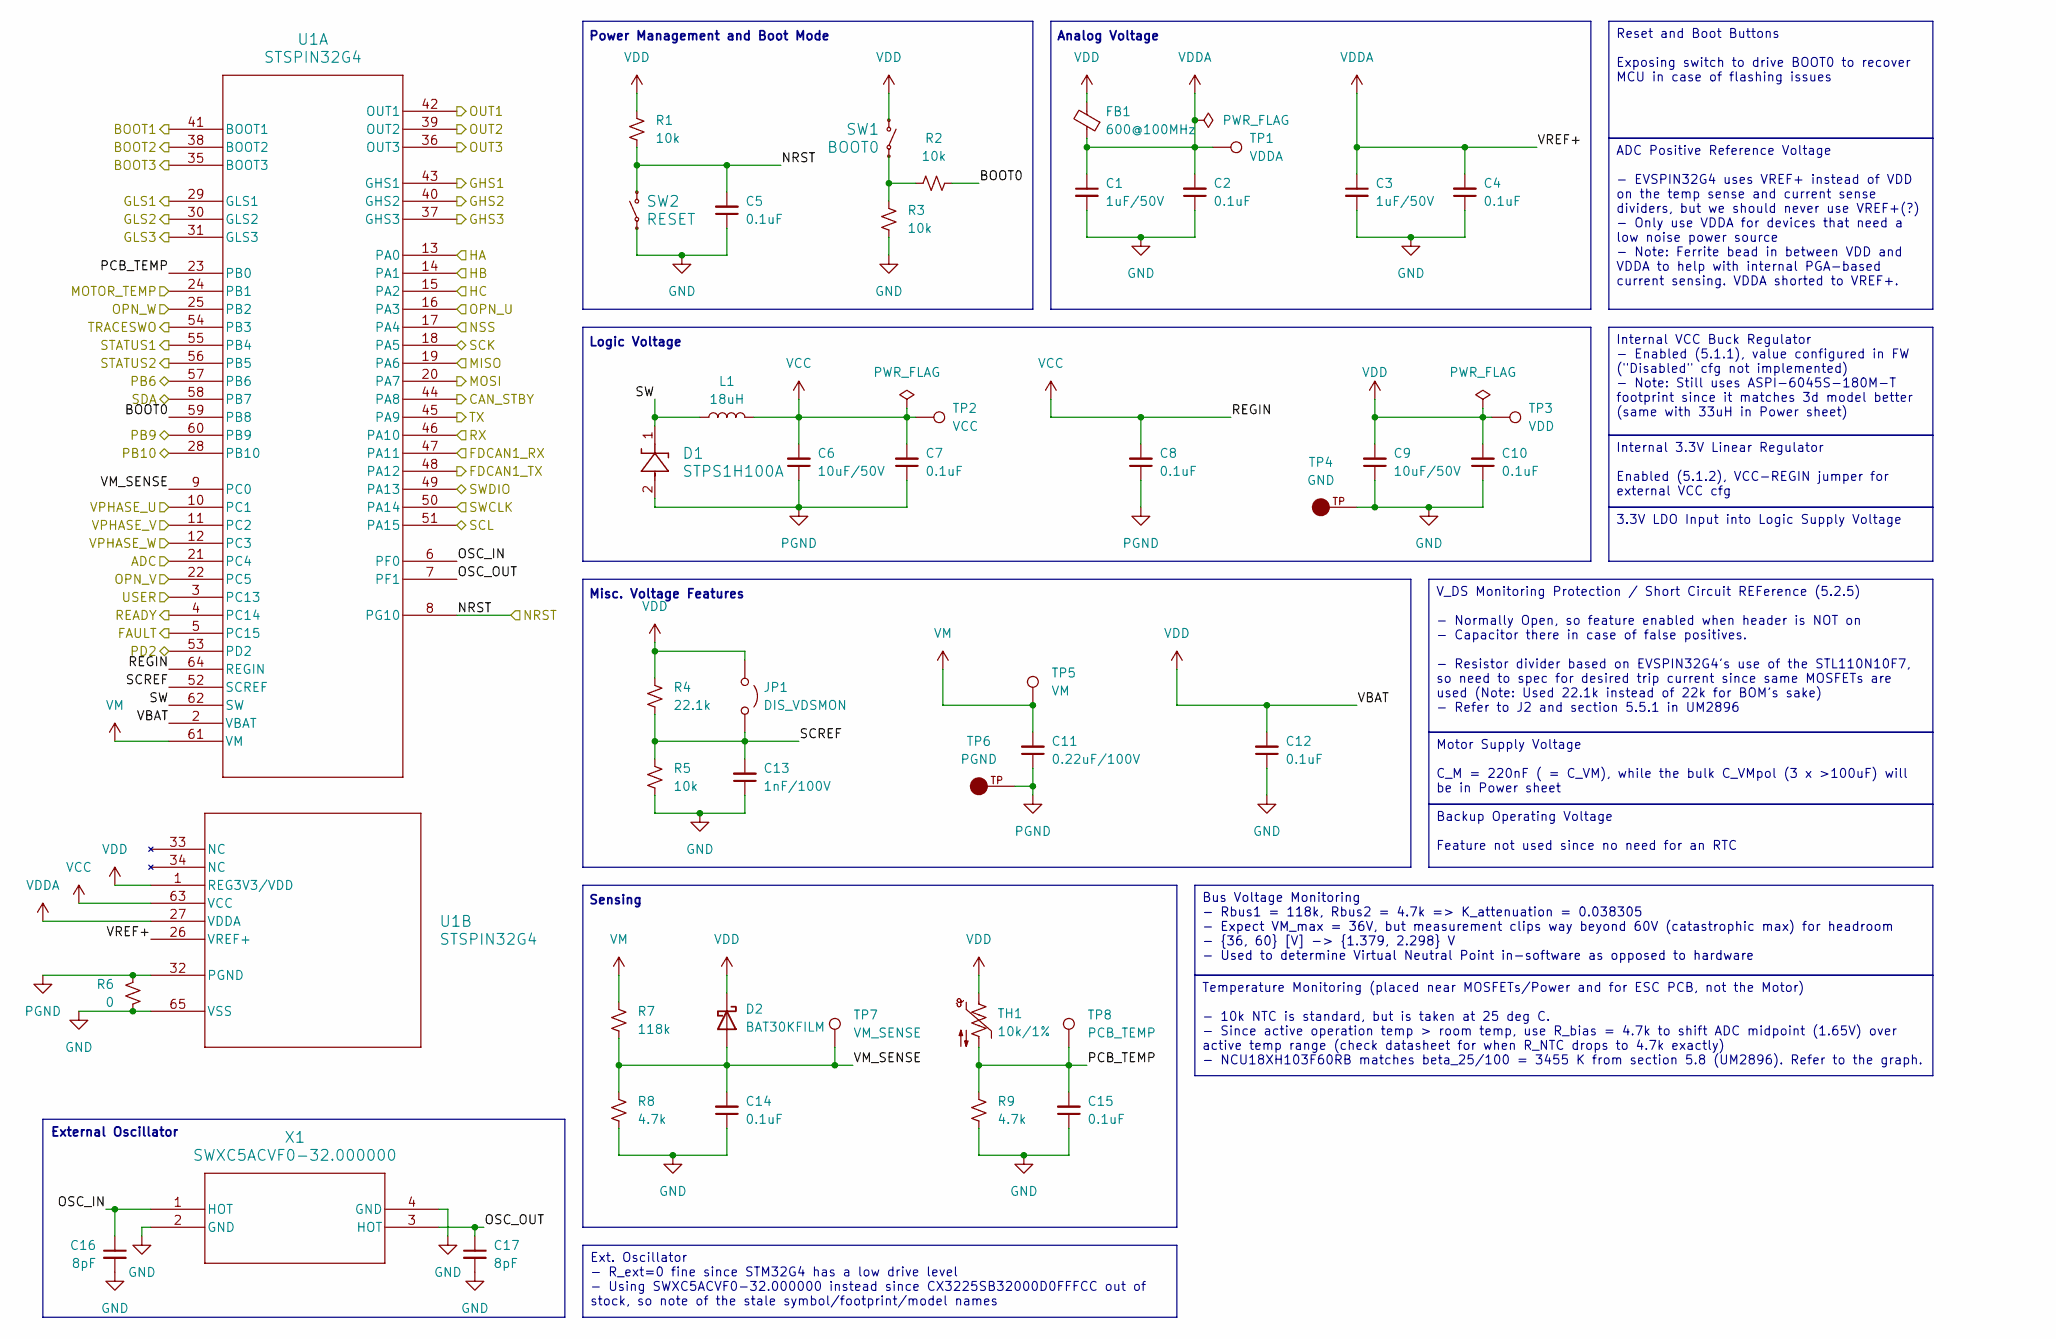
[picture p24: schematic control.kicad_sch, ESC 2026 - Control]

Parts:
C1, C3: 1uF/50V; C_0603_1608Metric; LCSC C15849
C2, C4, C5, C7, C8, C10, C12, C14, C15: 0.1uF; C_0603_1608Metric; LCSC C15725
C6, C9: 10uF/50V; C_0805_2012Metric; LCSC C440198
C11: 0.22uF/100V; C_0603_1608Metric; LCSC C2169715
C13: 1nF/100V; C_0603_1608Metric; LCSC C113793
C16, C17: 8pF; C_0603_1608Metric; LCSC C519117
D1: STPS1H100A; SMA_STM; LCSC C165701
D2: BAT30KFILM; D_SOD-523; LCSC C2926449
FB1: 600@100MHz; L_0603_1608Metric; LCSC C304319
JP1: DIS_VDSMON; PinHeader_1x02_P2.54mm_Vertical; LCSC C5426960
L1: 18uH; L_Sunlord_SWPA6045S; LCSC C96954
R1, R2, R3, R5: 10k; R_0603_1608Metric; LCSC C25804
R4: 22.1k; R_0603_1608Metric; LCSC C25961
R6: 0; R_0603_1608Metric; LCSC C21189
R7: 118k; R_0603_1608Metric; LCSC C25806
R8, R9: 4.7k; R_0603_1608Metric; LCSC C23162
SW1: BOOT0; TS-1187A-B-A-B; LCSC C318884
SW2: RESET; TS-1187A-B-A-B; LCSC C318884
TH1: 10k/1%; R_0603_1608Metric; LCSC C440252
TP1: VDDA; TestPoint_Pad_D1.0mm_with_More_Clearance
TP2: VCC; TestPoint_Pad_D1.0mm_with_More_Clearance
TP3: VDD; TestPoint_Pad_D1.0mm_with_More_Clearance
TP4: GND; KEYSTONE_5016; PARTREV D; DigiKey_Part_Number 36-5016CT-ND
TP5: VM; TestPoint_Pad_D1.0mm_with_More_Clearance
TP6: PGND; KEYSTONE_5016; PARTREV D; DigiKey_Part_Number 36-5016CT-ND
TP7: VM_SENSE; TestPoint_Pad_D1.0mm_with_More_Clearance
TP8: PCB_TEMP; TestPoint_Pad_D1.0mm_with_More_Clearance
U1: STSPIN32G4; QFN_IN32G4_STM; LCSC C7434864
X1: SWXC5ACVF0-32.000000; xtal4_CX3225SB_AVX; LCSC C22399832

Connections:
/Control/ADC: U1.21 (PC4); also elsewhere on the board
/Control/BOOT0: R2.2, U1.59 (PB8)
/Control/BOOT1: U1.41 (BOOT1); also elsewhere on the board
/Control/BOOT2: U1.38 (BOOT2); also elsewhere on the board
/Control/BOOT3: U1.35 (BOOT3); also elsewhere on the board
/Control/CAN_STBY: U1.44 (PA8); also elsewhere on the board
/Control/FAULT: U1.5 (PC15); also elsewhere on the board
/Control/FDCAN1_RX: U1.47 (PA11); also elsewhere on the board
/Control/FDCAN1_TX: U1.48 (PA12); also elsewhere on the board
/Control/GHS1: U1.43 (GHS1); also elsewhere on the board
/Control/GHS2: U1.40 (GHS2); also elsewhere on the board
/Control/GHS3: U1.37 (GHS3); also elsewhere on the board
/Control/GLS1: U1.29 (GLS1); also elsewhere on the board
/Control/GLS2: U1.30 (GLS2); also elsewhere on the board
/Control/GLS3: U1.31 (GLS3); also elsewhere on the board
/Control/HA: U1.13 (PA0); also elsewhere on the board
/Control/HB: U1.14 (PA1); also elsewhere on the board
/Control/HC: U1.15 (PA2); also elsewhere on the board
/Control/MISO: U1.19 (PA6); also elsewhere on the board
/Control/MOSI: U1.20 (PA7); also elsewhere on the board
/Control/MOTOR_TEMP: U1.24 (PB1); also elsewhere on the board
/Control/NRST: C5.2, R1.2, SW2.1, SW2.2, U1.8 (PG10); also elsewhere on the board
/Control/NSS: U1.17 (PA4); also elsewhere on the board
/Control/OPN_U: U1.16 (PA3); also elsewhere on the board
/Control/OPN_V: U1.22 (PC5); also elsewhere on the board
/Control/OPN_W: U1.25 (PB2); also elsewhere on the board
/Control/OSC_IN: C16.1, U1.6 (PF0), X1.1 (HOT)
/Control/OSC_OUT: C17.1, U1.7 (PF1), X1.3 (HOT)
/Control/PB6: U1.57 (PB6); also elsewhere on the board
/Control/PB9: U1.60 (PB9); also elsewhere on the board
/Control/PB10: U1.28 (PB10); also elsewhere on the board
/Control/PCB_TEMP: C15.2, R9.1, TH1.2, TP8.1 (1_1), U1.23 (PB0)
/Control/PD2: U1.53 (PD2); also elsewhere on the board
/Control/READY: U1.4 (PC14); also elsewhere on the board
/Control/RX: U1.46 (PA10); also elsewhere on the board
/Control/SCK: U1.18 (PA5); also elsewhere on the board
/Control/SCL: U1.51 (PA15); also elsewhere on the board
/Control/SCREF: C13.2, JP1.2 (B), R4.2, R5.1, U1.52 (SCREF)
/Control/SDA: U1.58 (PB7); also elsewhere on the board
/Control/STATUS1: U1.55 (PB4); also elsewhere on the board
/Control/STATUS2: U1.56 (PB5); also elsewhere on the board
/Control/SW: D1.1, L1.1, U1.62 (SW)
/Control/SWCLK: U1.50 (PA14); also elsewhere on the board
/Control/SWDIO: U1.49 (PA13); also elsewhere on the board
/Control/TRACESWO: U1.54 (PB3); also elsewhere on the board
/Control/TX: U1.45 (PA9); also elsewhere on the board
/Control/USER: U1.3 (PC13); also elsewhere on the board
/Control/VM_SENSE: C14.2, D2.2 (A), R7.2, R8.1, TP7.1 (1_1), U1.9 (PC0)
/Control/VPHASE_U: U1.10 (PC1); also elsewhere on the board
/Control/VPHASE_V: U1.11 (PC2); also elsewhere on the board
/Control/VPHASE_W: U1.12 (PC3); also elsewhere on the board
/Drive/U: U1.42 (OUT1); also elsewhere on the board
/Drive/V: U1.39 (OUT2); also elsewhere on the board
/Drive/W: U1.36 (OUT3); also elsewhere on the board
GND: C1.2, C2.1, C3.2, C4.1, C5.1, C9.1, C10.1, C12.1, C13.1, C14.1, C15.1, C16.2, C17.2, R3.2, R5.2, R6.1, R8.2, R9.2, SW2.3, SW2.4, TP4.TP, U1.65 (VSS), X1.2 (GND), X1.4 (GND); also elsewhere on the board
unnamed: R2.1, R3.1, SW1.3, SW1.4
PGND: C6.1, C7.1, C8.1, C11.1, D1.2, R6.2, TP6.TP, U1.32 (PGND); also elsewhere on the board
VCC: C6.2, C7.2, C8.2, L1.2, TP2.1 (1_1), U1.63 (VCC), U1.64 (REGIN); also elsewhere on the board
VDD: C9.2, C10.2, C12.2, D2.1 (K), FB1.2, JP1.1 (A), R1.1, R4.1, SW1.1, SW1.2, TH1.1, TP3.1 (1_1), U1.1 (REG3V3/VDD), U1.2 (VBAT); also elsewhere on the board
VDDA: C1.1, C2.2, C3.1, C4.2, FB1.1, TP1.1 (1_1), U1.26 (VREF+), U1.27 (VDDA)
VM: C11.2, R7.1, TP5.1 (1_1), U1.61 (VM); also elsewhere on the board

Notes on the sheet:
Analog Voltage
Misc. Voltage Features
Logic Voltage
Sensing
Power Management and Boot Mode
External Oscillator
Backup Operating Voltage Feature not used since no need for an RTC
3.3V LDO Input into Logic Supply Voltage
V_DS Monitoring Protection / Short Circuit REFerence (5.2.5) - Normally Open, so feature enabled when header is NOT on - Capacitor there in case of false positives. - Resistor divider based on EVSPIN32G4's use of the STL110N10F7, so need to spec for desired trip current since same MOSFETs are used 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
Internal 3.3V Linear Regulator Enabled (5.1.2), VCC-REGIN jumper for external VCC cfg
Internal VCC Buck Regulator - Enabled (5.1.1), value configured in FW ("Disabled" cfg not implemented) - Note: Still uses ASPI-6045S-180M-T footprint since it matches 3d model better (same with 33uH in Power sheet)
Temperature Monitoring (placed near MOSFETs/Power and for ESC PCB, not the Motor) - 10k NTC is standard, but is taken at 25 deg C. - Since active operation temp > room temp, use R_bias = 4.7k to shift ADC midpoint (1.65V) over active temp range (check datasheet for when R_NTC drops to 4.7k exactly)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
ADC Positive Reference Voltage - EVSPIN32G4 uses VREF+ instead of VDD on the temp sense and current sense dividers, but we should never use VREF+(?) - Only use VDDA for devices that need a low noise power source - Note: Ferrite bead in between VDD and VDDA to help with internal PGA-based current se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
Ext. Oscillator - R_ext=0 fine since STM32G4 has a low drive level - Using SWXC5ACVF0-32.000000 instead since CX3225SB32000D0FFFCC out of stock, so note of the stale symbol/footprint/model names
Motor Supply Voltage C_M = 220nF ( = C_VM), while the bulk C_VMpol (3 x >100uF) will be in Power sheet
Reset and Boot Buttons Exposing switch to drive BOOT0 to recover MCU in case of flashing issues
Bus Voltage Monitoring - Rbus1 = 118k, Rbus2 = 4.7k => K_attenuation = 0.038305 - Expect VM_max = 36V, but measurement clips way beyond 60V (catastrophic max) for headroom - {36, 60} [V] -> {1.379, 2.298} V - Used to determine Virtual Neutral Point in-software as opposed to hardware

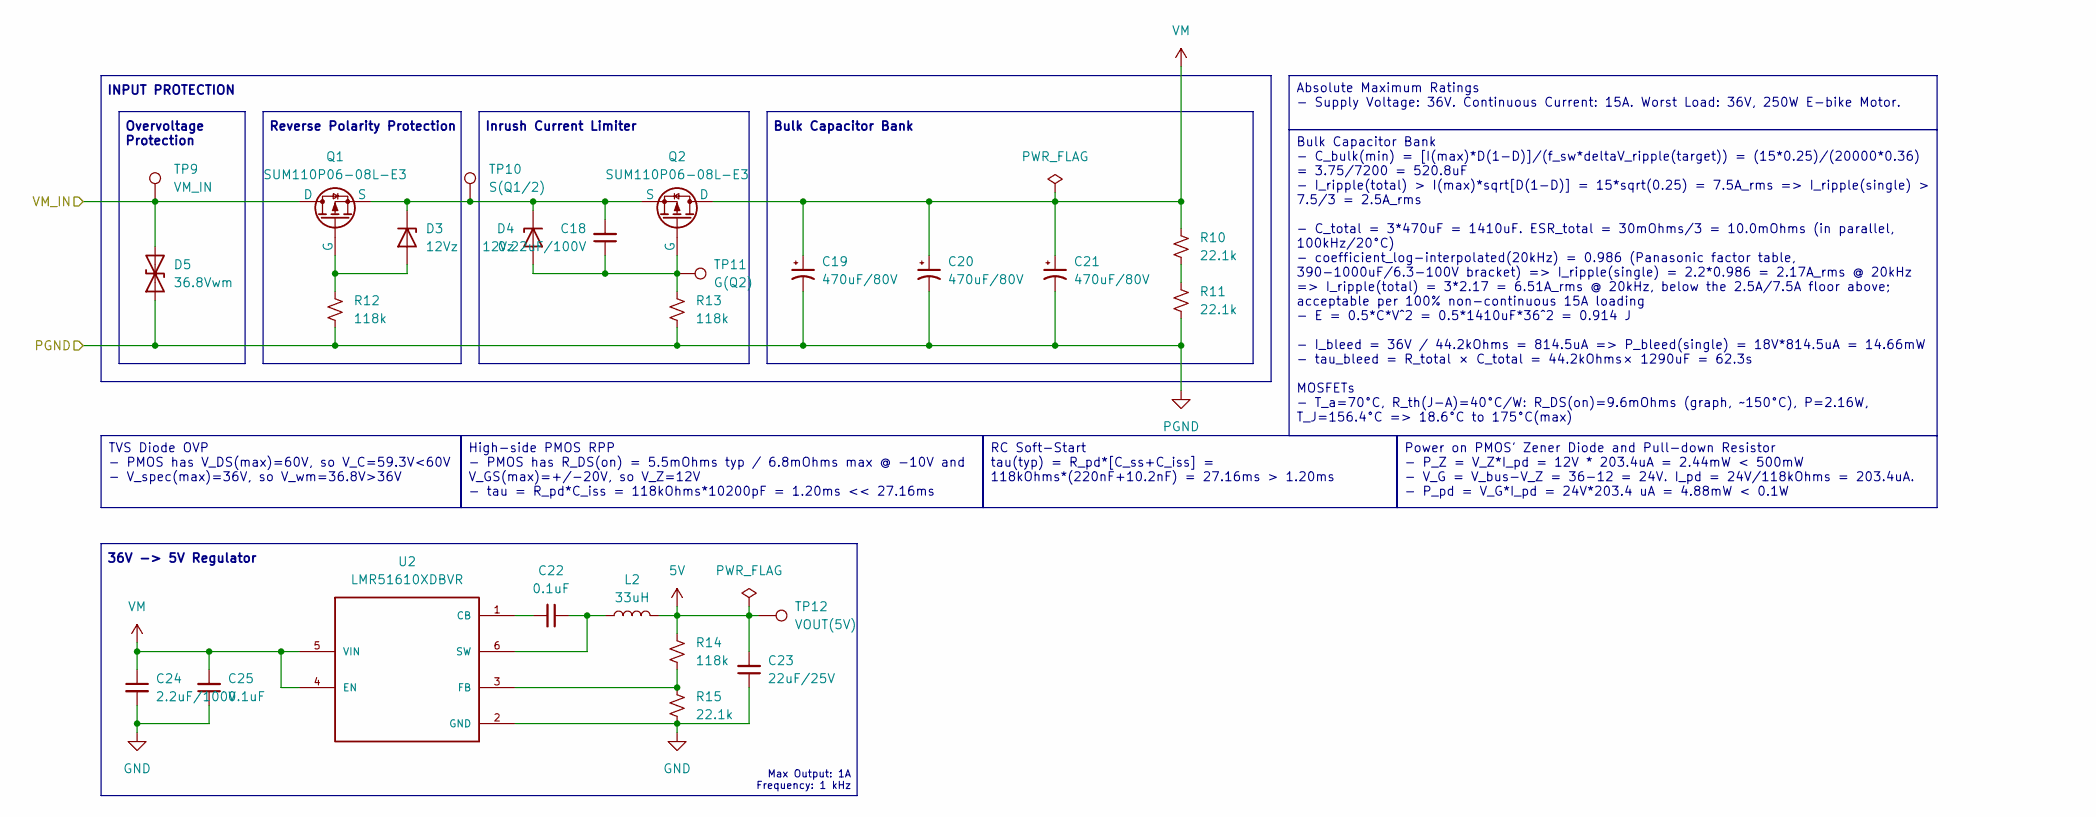
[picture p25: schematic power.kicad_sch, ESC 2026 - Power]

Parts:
C18: 0.22uF/100V; C_0603_1608Metric; LCSC C2169715
C19, C20, C21: 470uF/80V; CP_Radial_D12.5mm_P5.00mm; LCSC C385881
C22, C25: 0.1uF; C_0603_1608Metric; LCSC C15725
C23: 22uF/25V; C_0805_2012Metric; LCSC C45783
C24: 2.2uF/100V; C_0805_2012Metric; LCSC C2981733
D3, D4: 12Vz; D_SOD-123; LCSC C699126
D5: 36.8Vwm; D_SMB; LCSC C468909
L2: 33uH; L_Sunlord_SWPA6045S; LCSC C83451
Q1, Q2: SUM110P06-08L-E3; TO-263-2; LCSC C5364638
R10, R11, R15: 22.1k; R_0603_1608Metric; LCSC C25961
R12, R13, R14: 118k; R_0603_1608Metric; LCSC C25806
TP9: VM_IN; TestPoint_Pad_D1.0mm_with_More_Clearance
TP10: S(Q1/2); TestPoint_Pad_D1.0mm_with_More_Clearance
TP11: G(Q2); TestPoint_Pad_D1.0mm_with_More_Clearance
TP12: VOUT(5V); TestPoint_Pad_D1.0mm_with_More_Clearance
U2: LMR51610XDBVR; LMR51610XDBVR-SOT95P280X145-6N; PARTREV B; LCSC C20539658

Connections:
5V: C23.2, L2.2, R14.1, TP12.1 (1_1); also elsewhere on the board
/Peripherals/VM_IN: D5.2 (A2), Q1.2 (D), TP9.1 (1_1); also elsewhere on the board
GND: C23.1, C24.2, C25.1, R15.2, U2.2 (GND); also elsewhere on the board
unnamed: D3.2 (A), Q1.1 (G), R12.1
unnamed: C18.2, D3.1 (K), D4.1 (K), Q1.3 (S), Q2.3 (S), TP10.1 (1_1)
unnamed: C18.1, D4.2 (A), Q2.1 (G), R13.1, TP11.1 (1_1)
unnamed: R10.2, R11.1
unnamed: C22.2, U2.1 (CB)
unnamed: R14.2, R15.1, U2.3 (FB)
unnamed: C22.1, L2.1, U2.6 (SW)
PGND: C19.2, C20.2, C21.2, D5.1 (A1), R11.2, R12.2, R13.2; also elsewhere on the board
VM: C19.1, C20.1, C21.1, C24.1, C25.2, Q2.2 (D), R10.1, U2.4 (EN), U2.5 (VIN); also elsewhere on the board

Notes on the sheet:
Overvoltage Protection
Max Output: 1A Frequency: 1 kHz
36V -> 5V Regulator
INPUT PROTECTION
Inrush Current Limiter
Bulk Capacitor Bank
Reverse Polarity Protection
RC Soft-Start tau(typ) = R_pd*[C_ss+C_iss] = 118kOhms*(220nF+10.2nF) = 27.16ms > 1.20ms
TVS Diode OVP - PMOS has V_DS(max)=60V, so V_C=59.3V<60V - V_spec(max)=36V, so V_wm=36.8V>36V
High-side PMOS RPP - PMOS has R_DS(on) = 5.5mOhms typ / 6.8mOhms max @ -10V and V_GS(max)=+/-20V, so V_Z=12V - tau = R_pd*C_iss = 118kOhms*10200pF = 1.20ms << 27.16ms
Power on PMOS' Zener Diode and Pull-down Resistor - P_Z = V_Z*I_pd = 12V * 203.4uA = 2.44mW < 500mW - V_G = V_bus−V_Z = 36−12 = 24V. I_pd = 24V/118kOhms = 203.4uA. - P_pd = V_G*I_pd = 24V*203.4 uA = 4.88mW < 0.1W
Absolute Maximum Ratings - Supply Voltage: 36V. Continuous Current: 15A. Worst Load: 36V, 250W E-bike Motor.
Bulk Capacitor Bank - C_bulk(min) = [I(max)*D(1−D)]/(f_sw*deltaV_ripple(target)) = (15*0.25)/(20000*0.36) = 3.75/7200 = 520.8uF - I_ripple(total) > I(max)*sqrt[D(1−D)] = 15*sqrt(0.25) = 7.5A_rms => I_ripple(single) > 7.5/3 = 2.5A_rms - C_total = 3*470uF = 1410uF. ESR_total = 30mOhms/3 = 10.0mOhms (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

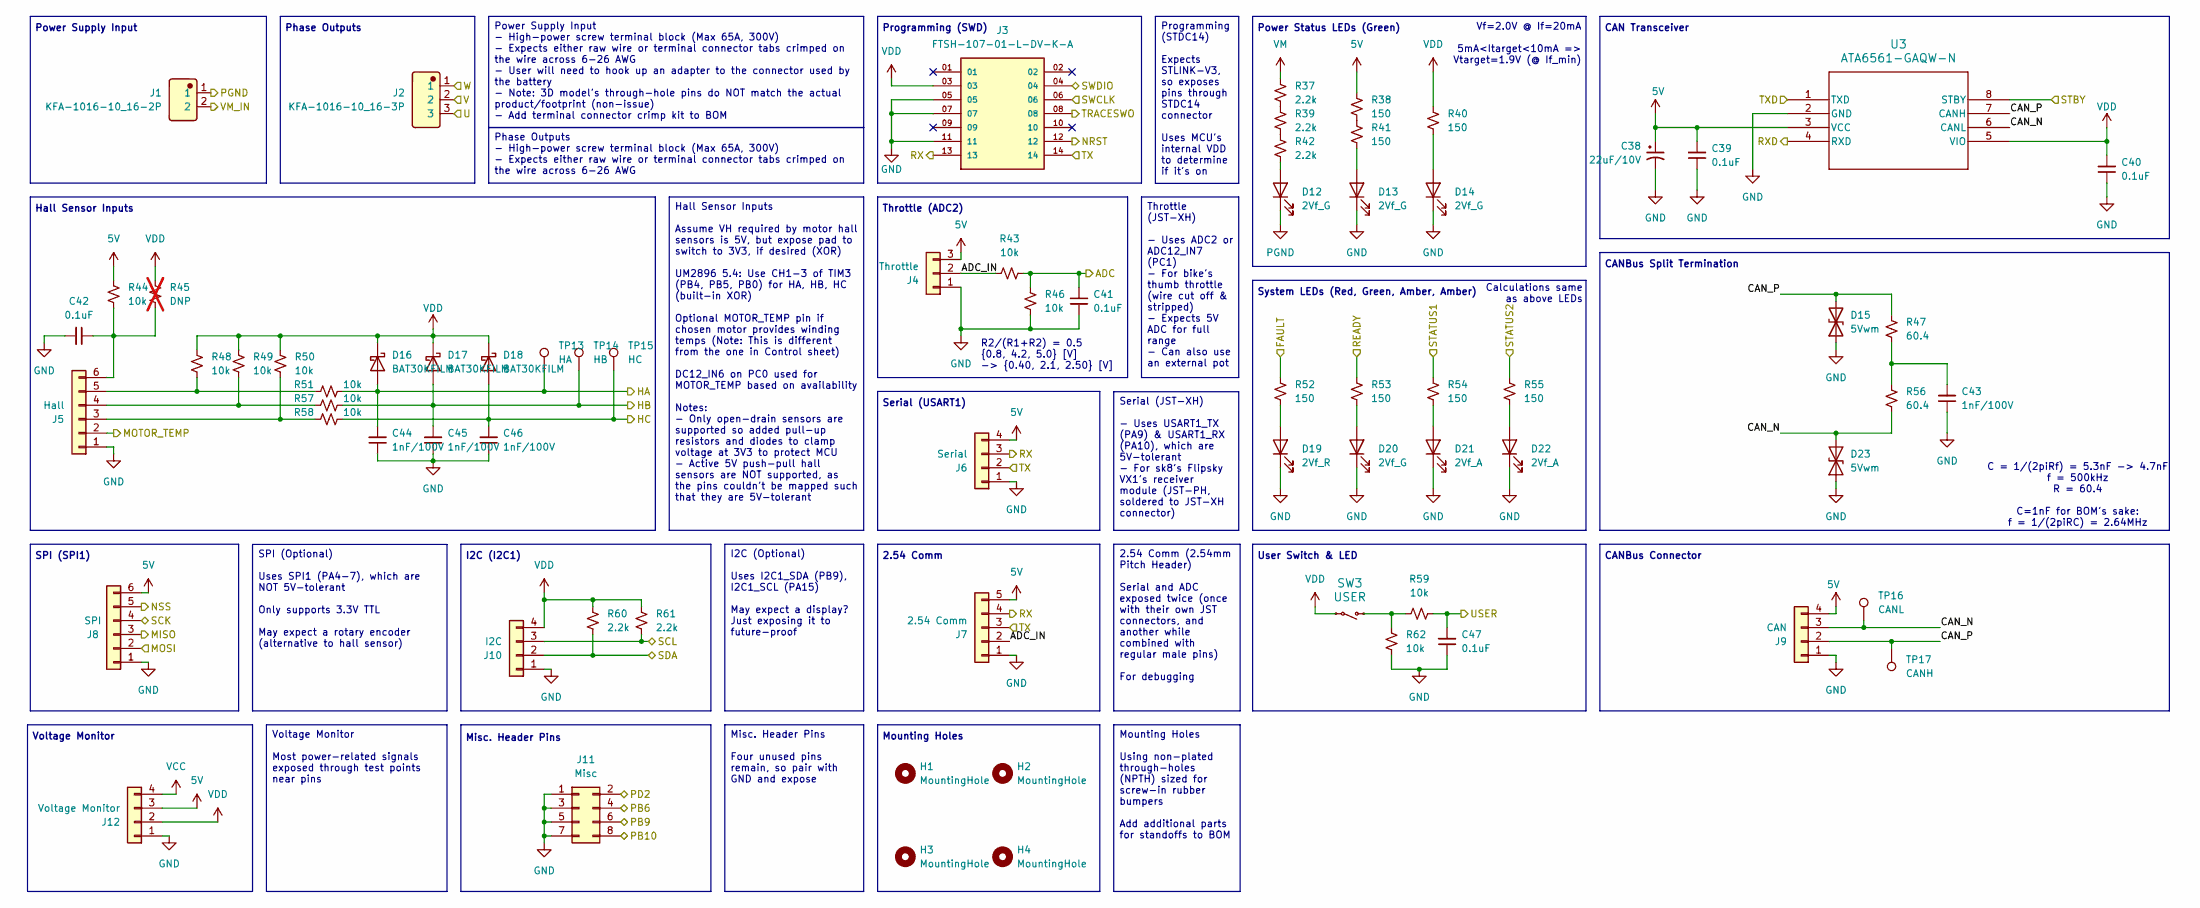
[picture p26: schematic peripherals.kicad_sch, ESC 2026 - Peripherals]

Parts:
C38: 22uF/10V; EEEFKC220UAR; LCSC C401733
C39, C40, C41, C42, C47: 0.1uF; C_0603_1608Metric; LCSC C15725
C43, C44, C45, C46: 1nF/100V; C_0603_1608Metric; LCSC C113793
D12, D13, D14, D20: 2Vf_G; LED_0603_1608Metric; LCSC C125098
D15, D23: 5Vwm; D_SOD-523; LCSC C51912417
D16, D17, D18: BAT30KFILM; D_SOD-523; LCSC C2926449
D19: 2Vf_R; LED_0603_1608Metric; LCSC C94869
D21, D22: 2Vf_A; LED_0603_1608Metric; LCSC C5730905
H1, H2, H3, H4: MountingHole; MountingHole_3.2mm_M3
J1: KFA-1016-10_16-2P; Manufacturer Part KFA-1016-10.16-2P; LCSC C475110
J2: KFA-1016-10_16-3P; Manufacturer Part KFA-1016-10.16-3P; LCSC C475111
J3: FTSH-107-01-L-DV-K-A; SAMTEC_FTSH-107-01-L-DV-K-A; PARTREV H; DigiKey_Part_Number FTSH-107-01-L-DV-K-A-ND
J4: Throttle; JST_XH_B3B-XH-A_1x03_P2.50mm_Vertical; LCSC C144394
J5: Hall; JST_XH_B6B-XH-A_1x06_P2.50mm_Vertical; LCSC C144397
J6: Serial; JST_XH_B4B-XH-A_1x04_P2.50mm_Vertical; LCSC C144395
J7: 2.54 Comm; PinHeader_1x05_P2.54mm_Vertical; LCSC C3347212
J8: SPI; PinHeader_1x06_P2.54mm_Vertical; LCSC C5427040
J9: CAN; JST_XH_B4B-XH-A_1x04_P2.50mm_Vertical; LCSC C144395
J10: I2C; PinHeader_1x04_P2.54mm_Vertical; LCSC C3329732
J11: Misc; PinHeader_2x04_P2.54mm_Vertical; LCSC C3333874
J12: Voltage Monitor; PinHeader_1x04_P2.54mm_Vertical; LCSC C3329732
R37, R39, R42, R60, R61: 2.2k; R_0603_1608Metric; LCSC C4190
R38, R40, R41, R52, R53, R54, R55: 150; R_0603_1608Metric; LCSC C22808
R43, R44, R46, R48, R49, R50, R51, R57, R58, R59, R62: 10k; R_0603_1608Metric; LCSC C25804
R45: DNP; R_0603_1608Metric; not fitted
R47, R56: 60.4; R_0603_1608Metric; LCSC C23090
SW3: USER; TS-1187A-B-A-B; LCSC C318884
TP13: HA; TestPoint_Pad_D1.0mm_with_More_Clearance
TP14: HB; TestPoint_Pad_D1.0mm_with_More_Clearance
TP15: HC; TestPoint_Pad_D1.0mm_with_More_Clearance
TP16: CANL; TestPoint_Pad_D1.0mm_with_More_Clearance
TP17: CANH; TestPoint_Pad_D1.0mm_with_More_Clearance
U3: ATA6561-GAQW-N; SOIC8_4P9X3P9MC_MCH; LCSC C616016

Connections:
5V: C38.1, C39.2, J4.3, J6.4, J7.5, J8.6, J9.4, J12.3, R38.1, R44.1, U3.3 (VCC); also elsewhere on the board
/Control/ADC: C41.1, R43.2, R46.2; also elsewhere on the board
/Control/CAN_STBY: U3.8 (STBY); also elsewhere on the board
/Control/FAULT: R52.1; also elsewhere on the board
/Control/FDCAN1_RX: U3.4 (RXD); also elsewhere on the board
/Control/FDCAN1_TX: U3.1 (TXD); also elsewhere on the board
/Control/HA: C44.2, D16.2 (A), R51.2, TP13.1 (1_1); also elsewhere on the board
/Control/HB: C45.2, D17.2 (A), R57.2, TP14.1 (1_1); also elsewhere on the board
/Control/HC: C46.2, D18.2 (A), R58.2, TP15.1 (1_1); also elsewhere on the board
/Control/MISO: J8.3; also elsewhere on the board
/Control/MOSI: J8.2; also elsewhere on the board
/Control/MOTOR_TEMP: J5.2; also elsewhere on the board
/Control/NRST: J3.12; also elsewhere on the board
/Control/NSS: J8.5; also elsewhere on the board
/Control/PB6: J11.4; also elsewhere on the board
/Control/PB9: J11.6; also elsewhere on the board
/Control/PB10: J11.8; also elsewhere on the board
/Control/PD2: J11.2; also elsewhere on the board
/Control/READY: R53.1; also elsewhere on the board
/Control/RX: J3.13, J6.3, J7.4; also elsewhere on the board
/Control/SCK: J8.4; also elsewhere on the board
/Control/SCL: J10.3, R61.1; also elsewhere on the board
/Control/SDA: J10.2, R60.1; also elsewhere on the board
/Control/STATUS1: R54.1; also elsewhere on the board
/Control/STATUS2: R55.1; also elsewhere on the board
/Control/SWCLK: J3.06; also elsewhere on the board
/Control/SWDIO: J3.04; also elsewhere on the board
/Control/TRACESWO: J3.08; also elsewhere on the board
/Control/TX: J3.14, J6.2, J7.3; also elsewhere on the board
/Control/USER: C47.2, R59.2; also elsewhere on the board
/Drive/U: J2.3; also elsewhere on the board
/Drive/V: J2.2; also elsewhere on the board
/Drive/W: J2.1; also elsewhere on the board
/Peripherals/ADC_IN: J4.2, J7.2, R43.1
/Peripherals/CAN_N: D23.2 (A2), J9.3, R56.2, TP16.1 (1_1), U3.6 (CANL)
/Peripherals/CAN_P: D15.2 (A2), J9.2, R47.1, TP17.1 (1_1), U3.7 (CANH)
/Peripherals/VM_IN: J1.2; also elsewhere on the board
GND: C38.2, C39.1, C40.1, C41.2, C42.2, C43.1, C44.1, C45.1, C46.1, C47.1, D13.1 (K), D14.1 (K), D15.1 (A1), D19.1 (K), D20.1 (K), D21.1 (K), D22.1 (K), D23.1 (A1), J3.05, J3.07, J3.11, J4.1, J5.1, J6.1, J7.1, J8.1, J9.1, J10.1, J11.1, J11.3, J11.5, J11.7, J12.1, R46.1, R62.2, U3.2 (GND); also elsewhere on the board
unnamed: C43.2, R47.2, R56.1
unnamed: D12.2 (A), R42.1
unnamed: D13.2 (A), R41.2
unnamed: D14.2 (A), R40.2
unnamed: D19.2 (A), R52.2
unnamed: D20.2 (A), R53.2
unnamed: D21.2 (A), R54.2
unnamed: D22.2 (A), R55.2
unnamed: J5.3, R50.2, R58.1
unnamed: J5.4, R49.2, R57.1
unnamed: J5.5, R48.2, R51.1
unnamed: C42.1, J5.6, R44.2, R45.2
unnamed: R37.1, R39.2
unnamed: R38.2, R41.1
unnamed: R39.1, R42.2
unnamed: R59.1, R62.1, SW3.1, SW3.2
PGND: D12.1 (K), J1.1; also elsewhere on the board
VCC: J12.4; also elsewhere on the board
VDD: C40.2, D16.1 (K), D17.1 (K), D18.1 (K), J3.03, J10.4, J12.2, R40.1, R45.1, R48.1, R49.1, R50.1, R60.2, R61.2, SW3.3, SW3.4, U3.5 (VIO); also elsewhere on the board
VM: R37.2; also elsewhere on the board

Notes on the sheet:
Vf=2.0V @ If=20mA 5mA<Itarget<10mA => Vtarget=1.9V (@ If_min)
CANBus Connector
C = 1/(2piRf) = 5.3nF -> 4.7nF f = 500kHz R = 60.4 C=1nF for BOM's sake: f = 1/(2piRC) = 2.64MHz
Power Supply Input
Mounting Holes
CANBus Split Termination
Programming (SWD)
CAN Transceiver
SPI (SPI1)
Misc. Header Pins
System LEDs (Red, Green, Amber, Amber)
Hall Sensor Inputs
R2/(R1+R2) = 0.5 {0.8, 4.2, 5.0} [V] -> {0.40, 2.1, 2.50} [V]
Calculations same as above LEDs
I2C (I2C1)
Serial (USART1)
2.54 Comm
Voltage Monitor
Power Status LEDs (Green)
Phase Outputs
User Switch & LED
Throttle (ADC2)
Hall Sensor Inputs Assume VH required by motor hall sensors is 5V, but expose pad to switch to 3V3, if desired (XOR) UM2896 5.4: Use CH1-3 of TIM3 (PB4, PB5, PB0) for HA, HB, HC (built-in XOR) Optional MOTOR_TEMP pin if chosen motor provides winding temps (Note: This is different from the one in Co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
Misc. Header Pins Four unused pins remain, so pair with GND and expose
Serial (JST-XH) - Uses USART1_TX (PA9) & USART1_RX (PA10), which are 5V-tolerant - For sk8's Flipsky VX1's receiver module (JST-PH, soldered to JST-XH connector)
Voltage Monitor Most power-related signals exposed through test points near pins
Programming (STDC14) Expects STLINK-V3, so exposes pins through STDC14 connector Uses MCU's internal VDD to determine if it's on
2.54 Comm (2.54mm Pitch Header) Serial and ADC exposed twice (once with their own JST connectors, and another while combined with regular male pins) For debugging
Phase Outputs - High-power screw terminal block (Max 65A, 300V) - Expects either raw wire or terminal connector tabs crimped on the wire across 6-26 AWG
I2C (Optional) Uses I2C1_SDA (PB9), I2C1_SCL (PA15) May expect a display? Just exposing it to future-proof
Throttle (JST-XH) - Uses ADC2 or ADC12_IN7 (PC1) - For bike's thumb throttle (wire cut off & stripped) - Expects 5V ADC for full range - Can also use an external pot
Power Supply Input - High-power screw terminal block (Max 65A, 300V) - Expects either raw wire or terminal connector tabs crimped on the wire across 6-26 AWG - User will need to hook up an adapter to the connector used by the battery - Note: 3D model's through-hole pins do NOT match the actual prod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
SPI (Optional) Uses SPI1 (PA4-7), which are NOT 5V-tolerant Only supports 3.3V TTL May expect a rotary encoder (alternative to hall sensor)
Mounting Holes Using non-plated through-holes (NPTH) sized for screw-in rubber bumpers Add additional parts for standoffs to BOM

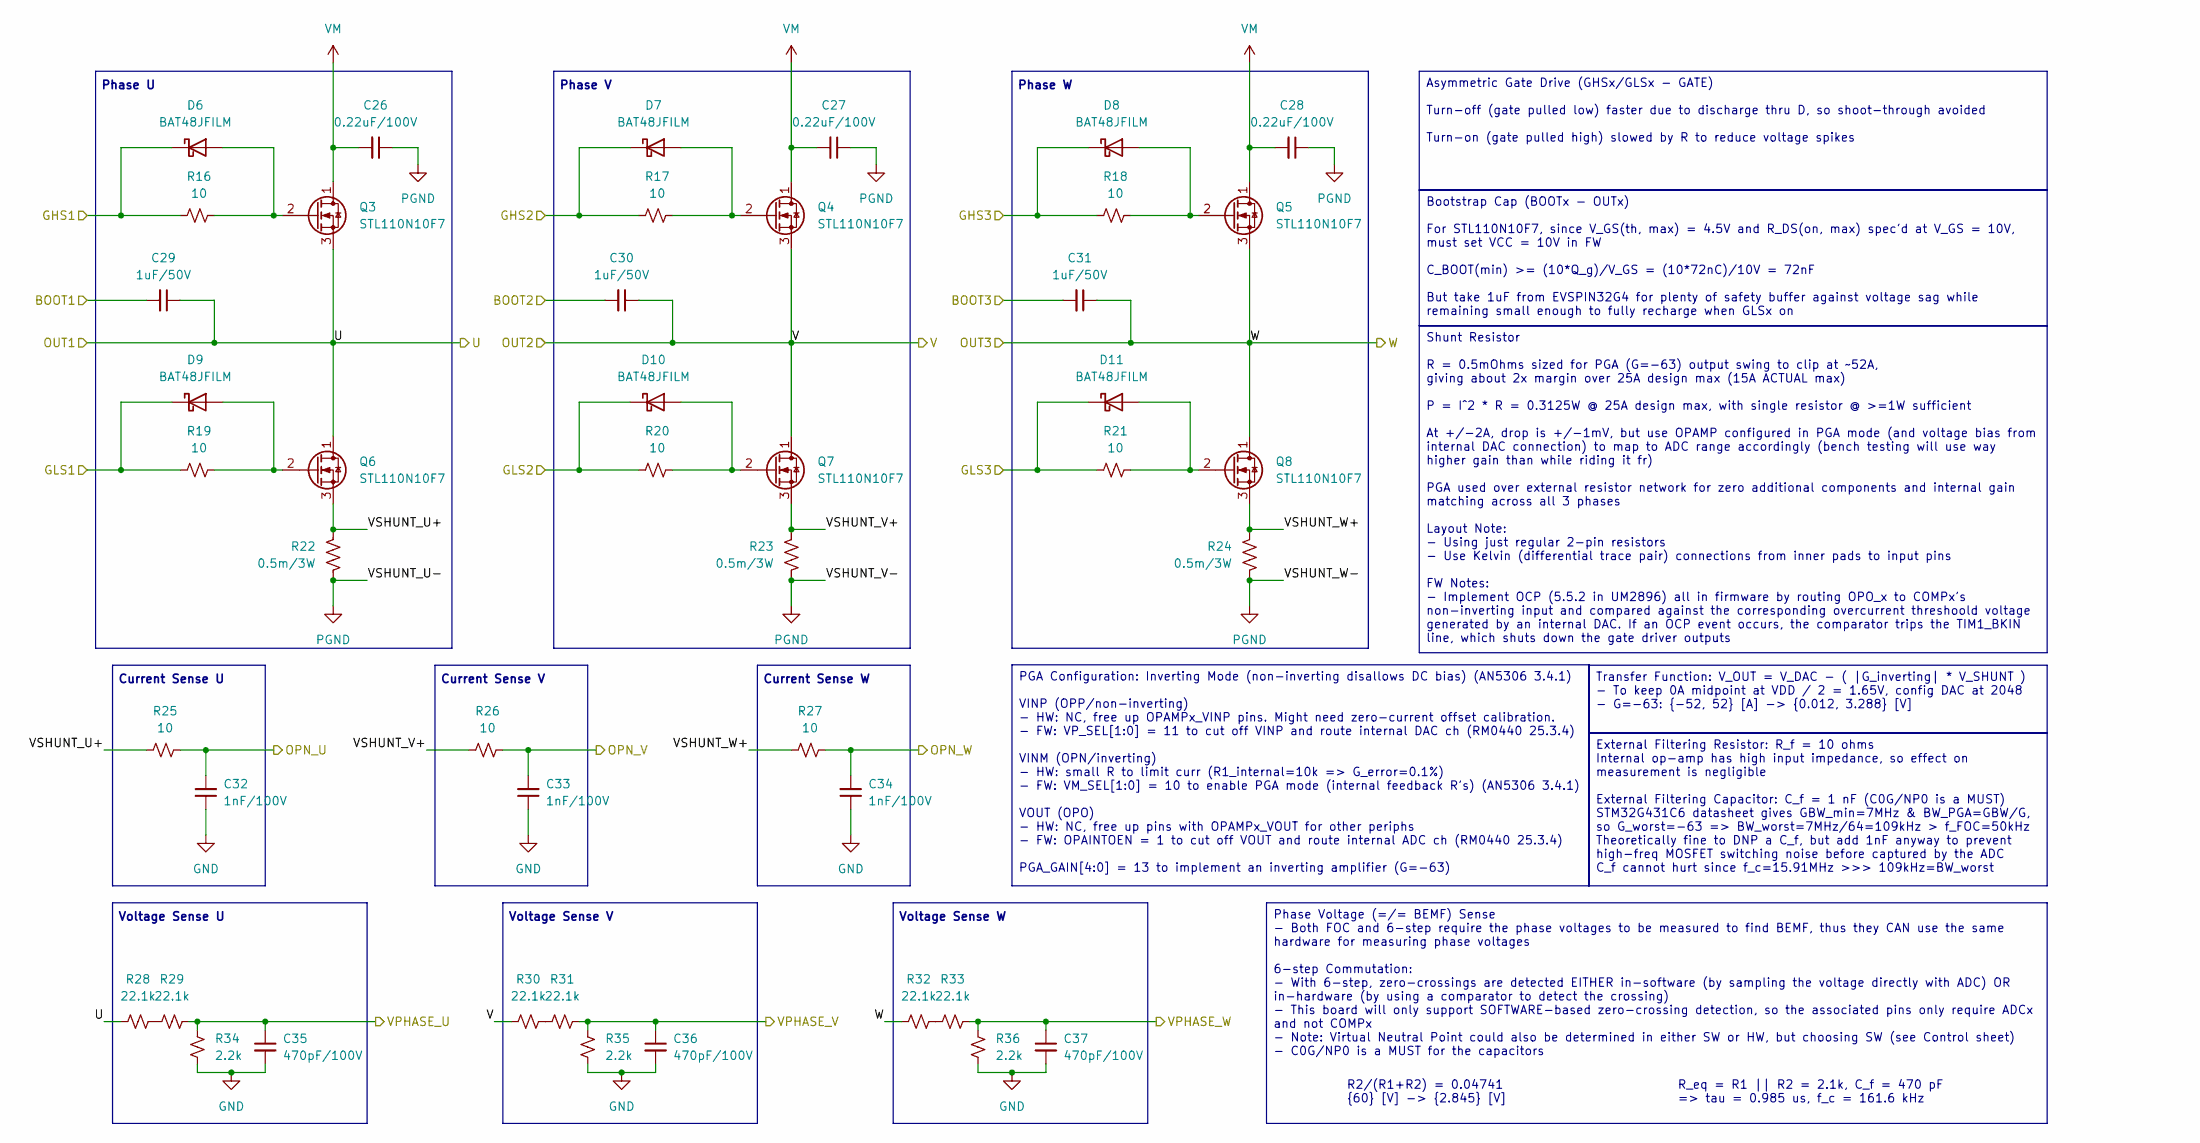
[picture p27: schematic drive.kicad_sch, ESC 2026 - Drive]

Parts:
C26, C27, C28: 0.22uF/100V; C_0603_1608Metric; LCSC C2169715
C29, C30, C31: 1uF/50V; C_0603_1608Metric; LCSC C15849
C32, C33, C34: 1nF/100V; C_0603_1608Metric; LCSC C113793
C35, C36, C37: 470pF/100V; C_0603_1608Metric; LCSC C326973
D6, D7, D8, D9, D10, D11: BAT48JFILM; D_SOD-323; LCSC C2798199
Q3, Q4, Q5, Q6, Q7, Q8: STL110N10F7; MOSFET_10N10F7_STM; LCSC C672185
R16, R17, R18, R19, R20, R21, R25, R26, R27: 10; R_0603_1608Metric; LCSC C22859
R22, R23, R24: 0.5m/3W; R_2512_6332Metric; LCSC C53447178
R28, R29, R30, R31, R32, R33: 22.1k; R_0603_1608Metric; LCSC C25961
R34, R35, R36: 2.2k; R_0603_1608Metric; LCSC C4190

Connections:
/Control/BOOT1: C29.2; also elsewhere on the board
/Control/BOOT2: C30.2; also elsewhere on the board
/Control/BOOT3: C31.2; also elsewhere on the board
/Control/GHS1: D6.1 (K), R16.1; also elsewhere on the board
/Control/GHS2: D7.1 (K), R17.1; also elsewhere on the board
/Control/GHS3: D8.1 (K), R18.1; also elsewhere on the board
/Control/GLS1: D9.1 (K), R19.1; also elsewhere on the board
/Control/GLS2: D10.1 (K), R20.1; also elsewhere on the board
/Control/GLS3: D11.1 (K), R21.1; also elsewhere on the board
/Control/OPN_U: C32.2, R25.2; also elsewhere on the board
/Control/OPN_V: C33.2, R26.2; also elsewhere on the board
/Control/OPN_W: C34.2, R27.2; also elsewhere on the board
/Control/VPHASE_U: C35.1, R29.2, R34.2; also elsewhere on the board
/Control/VPHASE_V: C36.1, R31.2, R35.2; also elsewhere on the board
/Control/VPHASE_W: C37.1, R33.2, R36.2; also elsewhere on the board
/Drive/U: C29.1, Q3.3 (S), Q6.1 (D), R28.1; also elsewhere on the board
/Drive/V: C30.1, Q4.3 (S), Q7.1 (D), R30.1; also elsewhere on the board
/Drive/VSHUNT_U+: Q6.3 (S), R22.1, R25.1
/Drive/VSHUNT_V+: Q7.3 (S), R23.1, R26.1
/Drive/VSHUNT_W+: Q8.3 (S), R24.1, R27.1
/Drive/W: C31.1, Q5.3 (S), Q8.1 (D), R32.1; also elsewhere on the board
GND: C32.1, C33.1, C34.1, C35.2, C36.2, C37.2, R34.1, R35.1, R36.1; also elsewhere on the board
unnamed: D6.2 (A), Q3.2 (G), R16.2
unnamed: D7.2 (A), Q4.2 (G), R17.2
unnamed: D8.2 (A), Q5.2 (G), R18.2
unnamed: D9.2 (A), Q6.2 (G), R19.2
unnamed: D10.2 (A), Q7.2 (G), R20.2
unnamed: D11.2 (A), Q8.2 (G), R21.2
unnamed: R28.2, R29.1
unnamed: R30.2, R31.1
unnamed: R32.2, R33.1
PGND: C26.1, C27.1, C28.1, R22.2, R23.2, R24.2; also elsewhere on the board
VM: C26.2, C27.2, C28.2, Q3.1 (D), Q4.1 (D), Q5.1 (D); also elsewhere on the board

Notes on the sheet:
Phase V
Voltage Sense V
Voltage Sense U
R2/(R1+R2) = 0.04741 {60} [V] -> {2.845} [V]
Voltage Sense W
Phase U
R_eq = R1 || R2 = 2.1k, C_f = 470 pF => tau = 0.985 us, f_c = 161.6 kHz
Current Sense V
Phase W
Current Sense W
Current Sense U
Bootstrap Cap (BOOTx - OUTx) For STL110N10F7, since V_GS(th, max) = 4.5V and R_DS(on, max) spec'd at V_GS = 10V, must set VCC = 10V in FW C_BOOT(min) >= (10*Q_g)/V_GS = (10*72nC)/10V = 72nF But take 1uF from EVSPIN32G4 for plenty of safety buffer against voltage sag while remaining small enough to 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
Phase Voltage (=/= BEMF) Sense - Both FOC and 6-step require the phase voltages to be measured to find BEMF, thus they CAN use the same hardware for measuring phase voltages 6-step Commutation: - With 6-step, zero-crossings are detected EITHER in-software (by sampling the voltage directly with ADC)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
PGA Configuration: Inverting Mode (non-inverting disallows DC bias) (AN5306 3.4.1) VINP (OPP/non-inverting) - HW: NC, free up OPAMPx_VINP pins. Might need zero-current offset calibration. - FW: VP_SEL[1:0] = 11 to cut off VINP and route internal DAC ch (RM0440 25.3.4) VINM (OPN/inverting) - HW: sma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
Transfer Function: V_OUT = V_DAC - ( |G_inverting| * V_SHUNT ) - To keep 0A midpoint at VDD / 2 = 1.65V, config DAC at 2048 - G=-63: {-52, 52} [A] -> {0.012, 3.288} [V]
Asymmetric Gate Drive (GHSx/GLSx - GATE) Turn-off (gate pulled low) faster due to discharge thru D, so shoot-through avoided Turn-on (gate pulled high) slowed by R to reduce voltage spikes
External Filtering Resistor: R_f = 10 ohms Internal op-amp has high input impedance, so effect on measurement is negligible External Filtering Capacitor: C_f = 1 nF (C0G/NP0 is a MUST) STM32G431C6 datasheet gives GBW_min=7MHz & BW_PGA=GBW/G, so G_worst=-63 => BW_worst=7MHz/64=109kHz > f_FOC=50kHz T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
Shunt Resistor R = 0.5mOhms sized for PGA (G=-63) output swing to clip at ~52A, giving about 2x margin over 25A design max (15A ACTUAL max) P = I^2 * R = 0.3125W @ 25A design max, with single resistor @ >=1W sufficient At +/-2A, drop is +/-1mV, but use OPAMP configured in PGA mode (and voltage bias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

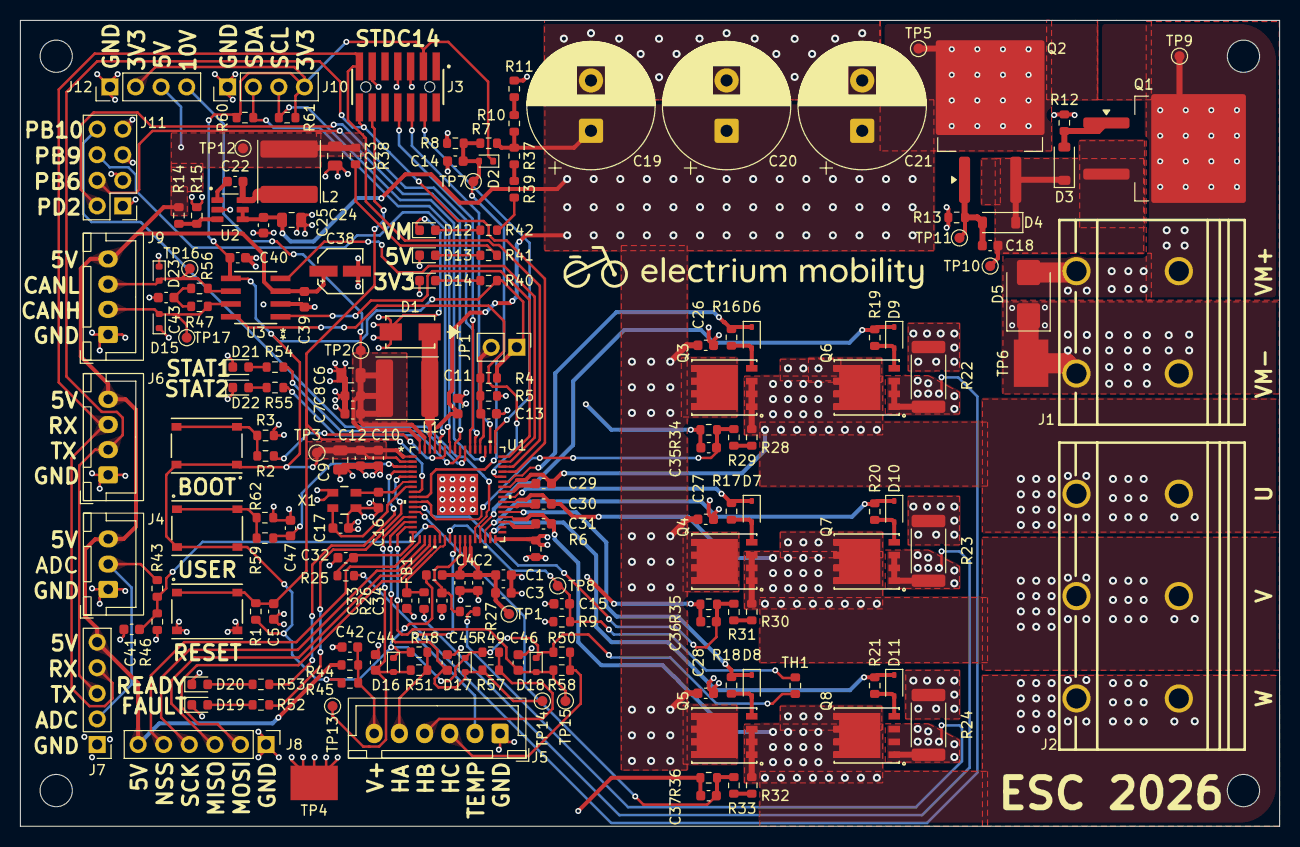
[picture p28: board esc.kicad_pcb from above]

Board: 4 copper layers, 125.0 x 80.0 mm, 185 parts (0 on the bottom side), 101 nets.

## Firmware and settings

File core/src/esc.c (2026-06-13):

/*******************************************************************************************************************************
 * @file   esc.c
 *
 * @brief  Source file for the ESC class
 *
 * @date   2026-01-31
 * @author Leopoldo Mendoza, 
 *******************************************************************************************************************************/

/* Standard library Headers */

/* Inter-component Headers */

/* Intra-component Headers */
#include "esc.h"

#include "trapezoidal.h"
#include "sensored.h"

/*******************************************************************************************************************************
 * Private Function Definitions
 *******************************************************************************************************************************/

// TODO STARTS: Feedback and Commutation Helpers
/**
 * @brief   Update feedback-derived estimates
 */
static void _esc_update_feedback(Esc_t *esc, uint32_t dt_us)
{
    if (esc == NULL || esc->is_initialized == false) {
        return;
    }

    switch (esc->config.feedback_mechanism) {
        case ESC_FEEDBACK_MECHANISM_SENSORED:
            sensored_update_feedback(esc, dt_us);
            break;

        case ESC_FEEDBACK_MECHANISM_SENSORLESS:
            /* Sensorless feedback is not implemented yet. */
            break;

        default:
            break;
    }
}

/**
 * @brief   Update inverter commutation step
 */
static void _esc_update_commutation(Esc_t *esc)
{
    if (esc == NULL || esc->is_initialized == false) {
        return;
    }

    switch (esc->config.commutation_method) {
        case ESC_COMMUTATION_METHOD_TRAP:
            esc->inverter_cmd.commutation_step = trapezoidal_hall_to_step(esc->motor_state.hall_abc & 0x07U);
            break;

        case ESC_COMMUTATION_METHOD_FOC:
            /* FOC commutation not implemented yet. */
            break;

        default:
            break;
    }
}
// TODO ENDS.

// TODO STARTS: Control and Output Helpers
/**
 * @brief   Update control target from throttle command
 */
static void _esc_update_setpoint(Esc_t *esc) {
    /* Check fault flags */
    if (esc->fault_flags != ESC_FAULT_NONE) {
        esc->velocity_setpoint_rpm = 0.0f;
        esc->torque_setpoint_A = 0.0f;
        return;
    }

    /* Clamp throttle to max values */
    float throttle = esc->throttle_cmd;
    if (throttle > THROTTLE_CMD_MAX) {
        throttle = THROTTLE_CMD_MAX;
    }
    if (throttle < THROTTLE_CMD_MIN) {
        throttle = THROTTLE_CMD_MIN;
    }

    /* Deadband */
    if (fabsf(throttle) < DEADBAND_THROTTLE) {
        throttle = 0.0f;
    }

    /* Calculating RPM & Torque from throttle */
    esc->torque_setpoint_A = throttle * MAX_PHASE_CURRENT;
    esc->velocity_setpoint_rpm = throttle * MAX_RPM;
    return;
}

/**
 * @brief   Check safety limits and update fault state
 */
static void _esc_check_limits(Esc_t *esc) {
    /* Check undervolt lockout */
    if (esc->motor_state.vbus_V < esc->config.limits.vbus_uvlo_V) {
        esc->fault_flags |= ESC_FAULT_UVLO;
    }
    /* Check overvolt lockout */
    if (esc->motor_state.vbus_V > esc->config.limits.vbus_ovlo_V) {
        esc->fault_flags |= ESC_FAULT_OVLO;
    }
    /* Check overtemp */
    if (esc->motor_state.temperature_C > esc->config.limits.max_temp_C) {
        esc->fault_flags |= ESC_FAULT_OVERTEMP;
    }
    /* Check all phase currents against maximum and update fault flags*/
    for (int i = 0; i < NUM_MOTOR_PHASES; ++i) {
        if (esc->motor_state.phase_currents_A[i] > 
            esc->config.limits.max_phase_current_A) {
            esc->fault_flags |= ESC_FAULT_OVERCURRENT;
            break;
        }
    }
    /* Hall invalidity is detected by the selected feedback mechanism. */

    /* All fault flag checks complete, return */
    return;
}

/**
 * @brief   Update inverter command outputs
 */
static void _esc_update_output(Esc_t *esc) {
    /* Check fault flags */
    if (esc->fault_flags != ESC_FAULT_NONE) {
        return;
    }

    /* Clamp throttle to max values */
    float throttle = esc->throttle_cmd;
    if (throttle > THROTTLE_CMD_MAX) {
        throttle = THROTTLE_CMD_MAX;
    }
    if (throttle < THROTTLE_CMD_MIN) {
        throttle = THROTTLE_CMD_MIN;
    }

    /* Find direction based on throttle input */
    bool reverse = 0;
    if (throttle < 0.0f) {
        reverse = 1;
    }

    /* Take duty as abs of throttle */
    float duty;
    if (throttle >= 0.0f) {
        duty = throttle;
    } else {
        duty = -throttle; 
    }

    /* Deadband */
    if (duty < DEADBAND_DUTY) {
        return;
    }

    uint8_t step = esc->inverter_cmd.commutation_step;

    /* WARNING: Reverse handelling may change in future. */
    /* Update direction by 180 degree electrical shift */
    if (reverse) {
        step = (step + 3) % 6;
    }

    /* Update inverter_cmd */
    esc->inverter_cmd.enable = true;
    esc->inverter_cmd.duty = duty * MAX_PWM_DUTY; /* Scaling to MAX_PWM_DUTY */
    esc->inverter_cmd.commutation_step = step;

    return;
}
// TODO ENDS.

/*******************************************************************************************************************************
 * Public Function Definitions
 *******************************************************************************************************************************/
void esc_step(Esc_t *esc, uint32_t dt_us)
{
    if (esc == NULL){
        return; //null pntr check
    }

    if (!esc->is_initialized){
        
        return; 
    }

    if (dt_us == 0U){
        return;
    }

    _esc_update_feedback(esc, dt_us);
    _esc_update_setpoint(esc);
    _esc_update_commutation(esc);
    _esc_check_limits(esc);
    _esc_update_output(esc);
}

void esc_set_throttle(Esc_t *esc, const float throttle_cmd) {
    /* Validate esc input */
    if (esc == NULL || esc->is_initialized == false) {
        return;
    }
    /* Clamp throttle command to valid range [THROTTLE_CMD_MIN, THROTTLE_CMD_MAX] */
    if (throttle_cmd > THROTTLE_CMD_MAX) {
        esc->throttle_cmd = THROTTLE_CMD_MAX;
    } else if (throttle_cmd < THROTTLE_CMD_MIN) {
        esc->throttle_cmd = THROTTLE_CMD_MIN;
    } else {
        esc->throttle_cmd = throttle_cmd;
    }
}

void esc_set_motor_state(Esc_t *esc, const MotorState_t *state) {
    /* Validate esc input */
    if (esc == NULL || esc->is_initialized == false || state == NULL) {
        return;
    }
    esc->motor_state = *state;
}
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

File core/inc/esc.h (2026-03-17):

#pragma once

/*******************************************************************************************************************************
 * @file   esc.h
 *
 * @brief  Header file for the ESC class
 *
 * @date   2026-01-31
 * @author Leopoldo Mendoza
 *******************************************************************************************************************************/

/* Standard library Headers */
#include <stdbool.h>
#include <stdint.h>
#include <math.h>

/* Inter-component Headers */

/* Intra-component Headers */
#include "motor.h"

/*******************************************************************************************************************************
 * Private defines and enums
 *******************************************************************************************************************************/
#define HALL_INVALID ((uint8_t)0xFFU)

/* Preprocessor definitions for config validity, subject to change. */
/* Set to zero temporarily */
#define OVERTEMP_THRESHOLD 75.0f /*75 degrees celcius*/
#define UNDERVOLT_LOCKOUT 0.0f
#define OVERVOLT_LOCKOUT 0.0f
#define MAX_PWM_DUTY 2000.0f /*2000 microseconds*/
#define MAX_RPM 0.0f
#define MAX_PHASE_CURRENT 0.0f 

/* Preprocessor definitions for ESC deadbands, subject to change. */
#define DEADBAND_THROTTLE 0.01f
#define DEADBAND_DUTY 0.02f

/* Preprocessor definitions for max and min throttle values*/
#define THROTTLE_CMD_MAX 1.0f
#define THROTTLE_CMD_MIN -1.0f

/* Preprocessor definitions for useful constants */
#define HALL_TRANSITIONS_PER_ELECTRICAL_REVOLUTION 6.0f
#define MICROSECONDS_PER_MINUTE 60000000.0f
#define MIN_PERIOD_BETWEEN_HALL_TRANSITIONS_US 10U /*10 microseconds*/

/**
 * @defgroup ESC ESC storage class
 * @brief    Electronic speed controller storage class
 * @{
 */

/**
 * @brief   ESC control modes
 */
typedef enum {
    ESC_CONTROL_MODE_VELOCITY, /**< Velocity Control */
    ESC_CONTROL_MODE_TORQUE,   /**< Torque Control */
    NUM_ESC_CONTROL_MODES
} EscControlMode_t;

/**
 * @brief   ESC commutation methods
 */
typedef enum {
    ESC_COMMUTATION_METHOD_TRAP, /**< Trapezoidal (6-step) */
    ESC_COMMUTATION_METHOD_FOC,  /**< Field-Oriented Control */
    NUM_ESC_COMMUTATION_METHODS
} EscCommutationMethod_t;

/**
 * @brief   ESC feedback mechanism
 */
typedef enum {
    ESC_FEEDBACK_MECHANISM_SENSORED,   /**< Sensored Feedback with Hall Effect Sensors */
    ESC_FEEDBACK_MECHANISM_SENSORLESS, /**< Sensorless Feedback with Back Electromotive Force (BEMF) */
    NUM_ESC_FEEDBACK_MECHANISMS
} EscFeedbackMechanism_t;

/**
 * @brief   ESC three-phase inverter command output class
 */
typedef struct {
    bool enable;              /**< Enable/Disable Three-Phase Inverter */
    float duty;               /**< PWM Duty Cycle */
    uint8_t commutation_step; /**< 6-step Commutation Index (0–5) */
} EscInverterCmd_t;

typedef struct {
    float max_phase_current_A; /**< Maximum allowed phase current */
    float max_temp_C;          /**< Overtemperature threshold */
    float vbus_uvlo_V;         /**< Undervoltage lockout threshold */
    float vbus_ovlo_V;         /**< Overvoltage lockout threshold */
    float max_duty;            /**< Maximum PWM Duty Cycle */
} EscLimits_t;

typedef enum {
    ESC_FAULT_NONE         = 0U,
    ESC_FAULT_UVLO         = (1U << 0),
    ESC_FAULT_OVLO         = (1U << 1),
    ESC_FAULT_OVERTEMP     = (1U << 2),
    ESC_FAULT_OVERCURRENT  = (1U << 3),
    ESC_FAULT_HALL_INVALID = (1U << 4),
} EscFault_t;

/**
 * @brief   ESC configuration class
 */
typedef struct {
    EscControlMode_t control_mode;
    EscCommutationMethod_t commutation_method;
    EscFeedbackMechanism_t feedback_mechanism;

    EscLimits_t limits;

    MotorConfig_t motor_config;
} EscConfig_t;

/**
 * @brief   ESC storage class
 */
typedef struct {
    EscConfig_t config;            /**< ESC configuration */

    MotorState_t motor_state;      /**< Motor measured state */
    EscInverterCmd_t inverter_cmd; /**< Inverter command output */

    /* Internal State During Runtime */
    float throttle_cmd;            /**< Last Throttle Command [-1.0, 1.0] */
    float velocity_setpoint_rpm;   /**< Desired Velocity (RPM) Value */
    float torque_setpoint_A;       /**< Desired Torque (Phase Current) Value */
    float velocity_mech_rpm;       /**< Estimated Mechanical Speed */
    uint32_t fault_flags;          /**< Active/Latching Faults Bitmask */

    bool is_initialized;           /**< ESC Initialized Flag */
} Esc_t;

/*******************************************************************************************************************************
 * Function declarations
 *******************************************************************************************************************************/

// TODO STARTS: Con/Destructors sorta
/**
 * @brief   Initialize ESC with a configuration
 * @param   esc ESC instance to initialize
 * @param   cfg Configuration to copy into ESC
 * @return  true if initialization succeeded, false otherwise
 */
bool esc_init(Esc_t *esc, const EscConfig_t *cfg);

/**
 * @brief   Reset ESC runtime state (clears faults and disables outputs)
 * @param   esc ESC instance
 */
void esc_reset(Esc_t *esc);

/**
 * @brief   Validate a configuration structure
 * @param   cfg Config to validate
 * @return  true if valid
 */
bool esc_config_is_valid(const EscConfig_t *cfg);
// TODO ENDS

// TODO STARTS: Control Loop (calls static funcs in esc.c)
/**
 * @brief   Main ESC update tick, which is called at a TBD frequency
 * @param   esc ESC instance
 * @param   dt_us Time since last tick in microseconds
 */
void esc_step(Esc_t *esc, uint32_t dt_us);
// TODO ENDS.

// TODO STARTS: Setters
/**
 * @brief   Set throttle command
 * @param   esc ESC instance
 * @param   throttle_cmd Throttle command in range [-1.0, 1.0]
 */
void esc_set_throttle(Esc_t *esc, float throttle_cmd);

/**
 * @brief   Update motor measured state (copied into esc->motor_state)
 * @param   esc ESC instance
 * @param   state Latest motor state sample
 */
void esc_set_motor_state(Esc_t *esc, const MotorState_t *state);
// TODO ENDS.

// TODO STARTS: Getters
/**
 * @brief   Get latest inverter command (enable/duty/comm step)
 * @param   esc ESC instance
 * @return  Current inverter command or a safe default {0} if invalid esc
 */
EscInverterCmd_t esc_get_inverter_cmd(const Esc_t *esc);

/**
 * @brief   Check whether ESC is faulted (any fault flag set)
 * @param   esc ESC instance
 * @return  true if faulted or uninitialized esc, false if no faults
 */
bool esc_is_faulted(const Esc_t *esc);

/**
 * @brief   Get current fault flags
 * @param   esc ESC instance
 * @return  Fault bitmask, or ESC_FAULT_NONE if invalid or not initialized esc
 */
EscFault_t esc_get_fault_flags(const Esc_t *esc);
// TODO ENDS.

/** @} */

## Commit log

2026-01-30 Set up KiCad project with blank hierarchical sheets!
    [control.kicad_sch, drive.kicad_sch, esc.kicad_pcb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]
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2026-02-09 Motor Interface / Config - Con/Deconstructors
    ESC initialization, ESC reset, ESC config validity + added preprocessor macros to esc.h subject to change
    [esc.c, esc.h]
2026-02-13 Resolving Pull Request Issues
    [esc.c, esc.h]
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2026-03-01 Made requested changes
    Added preprocessor macros for deadband values, and fixed blaring fault flag manipulation issues
    [esc.c, esc.h]
2026-03-04 Set up Drive schem
    [drive.kicad_sch, esc.kicad_sch]
2026-03-10 fixed according to the comments
    [power.kicad_sch]
2026-03-17 Done with Drive stage EXCEPT analog sensing
    [drive.kicad_sch, esc.kicad_sch]
2026-03-17 Added STM to Control sheet and proj libs
    [control.kicad_sch, drive.kicad_sch, esc.kicad_sch]
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2026-03-18 Cleaned up symbols and added footprint/3d model
    [control.kicad_sch, esc.kicad_sch, power.kicad_sch]
2026-03-19 Minor edits to KiCad files
    [drive.kicad_sch]
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2026-03-31 input protection schematic and simulations added
    [power.kicad_sch]
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2026-06-02 Adjusted notes in schem
    [drive.kicad_sch]
2026-06-13 Fix host state utils bug
    [host_test_utils.c]
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2026-06-14 filled out STSPIN32G4 for application circuitry
    [control.kicad_sch, drive.kicad_sch, esc.kicad_sch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]
2026-06-17 analog sensing
    3 possible options for opamps, bootstrap caps depend on mosfets, so i gave the formula for that in the kicad.
    [drive.kicad_sch]
2026-06-23 Revise Arnav's sensing task--changes to be made
    [drive.kicad_sch]
2026-06-24 Upgrade to Kicad 10!
    [control.kicad_sch, drive.kicad_sch, esc.kicad_pcb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]
2026-06-25 Replace drive sheet with latest
    [drive.kicad_sch]
2026-06-26 Updated local/hierarchical labels, renamed signals, and added alternate pin functions. Still need to review application circuit values fr.
    [control.kicad_sch, drive.kicad_sch, esc.kicad_sch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]
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2026-06-28 Clean up control sheet (no boxes yet)
    [control.kicad_sch, drive.kicad_sch, esc.kicad_sch]
2026-06-29 Add note about EPAD
    [control.kicad_sch]
2026-06-29 Add creds to control sheet
    [control.kicad_sch]
2026-06-29 changed bucks, added ldo and new power chip
    [power.kicad_sch]
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2026-06-30 fixed resistor values
    [power.kicad_sch]
2026-06-30 Update notes on half bridges and researched OPAMP PGA mode for current sense
    [drive.kicad_sch]
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2026-07-05 Finish current sense, but still need to remove control pin connections to VINP and VOUT
    [drive.kicad_sch]
2026-07-05 Revert old esc.kicad_sym before power schem revamp
2026-07-05 Remove VINP and VOUT pins, updated pin functions on VINM pins
    [control.kicad_sch, esc.kicad_sch]
2026-07-07 Add SWD/JTAG pin functions, not using JTAG doe
    [control.kicad_sch]
2026-07-07 changed power stage and fixed libraries
    [power.kicad_sch]
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2026-07-19 Revert peripherals sheet before esc-review
    [peripherals.kicad_sch]
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2026-07-19 Remove VREF+ as hierarchical label cuz PGA used now
    [control.kicad_sch, esc.kicad_sch]
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2026-07-21 Update root sheet with periph H labels, excluding LED signals
    [control.kicad_sch, esc.kicad_sch]
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2026-07-23 added peripherals main sheet and fixed erc errors
    [control.kicad_sch, drive.kicad_sch, esc.kicad_sch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]
2026-07-30 Change R19 in power stage from 10k to 50
    [power.kicad_sch]
2026-07-30 Resolve 'arrows' in control sheet AND changed R_ext on external crystal from 330 ohms to 0 ohms
    [control.kicad_sch]
2026-07-30 Add alt pin functions for OSC_IN and OSC_OUT
    [control.kicad_sch]
2026-07-30 Remove cap footprint on V_DS monitoring protection cct jumper
    [control.kicad_sch]
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2026-07-30 Revert changes to Serial hierarchical label names
    [peripherals.kicad_sch]
2026-07-30 Remove spec'd diodes and replace with original suggested parts
    [control.kicad_sch, drive.kicad_sch, esc.kicad_sch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]
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2026-07-30 Prep remaining tasks and show CAN + trimmer
    [peripherals.kicad_sch]
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2026-08-01 Ready to assign pins for periphs in MCU control sheet
    [peripherals.kicad_sch]
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2026-08-11 Rework power button to power slide switch, no footprint/part yetgit add .
    [peripherals.kicad_sch, power.kicad_sch]
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2026-08-12 Think about, but ultimately return, to the original hall sensor circuit. No footprints yet.
    [peripherals.kicad_sch]
2026-08-12 Add footprints to hall sensor section, but next time leaving passive footprints last
    [peripherals.kicad_sch]
2026-08-12 Deleting 5V to 3V3 LDO. Replace all references to net '3V3' with 'VDD.'
    [peripherals.kicad_sch, power.kicad_sch]
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2026-08-12 Clean up pins and reorg SPI and I2C
    [control.kicad_sch, esc.kicad_sch, peripherals.kicad_sch]
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2026-08-12 Fix LEDs next
    [peripherals.kicad_sch]
2026-08-13 Rework LEDs
    [peripherals.kicad_sch]
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2026-08-15 Finalize reset/power buttons and VDDA/VREF+
    [control.kicad_sch]
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2026-08-15 Finished control sheet sensing. Need to work on OSC tomorrow
    [control.kicad_sch, peripherals.kicad_sch]
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2026-08-18 Checkpoint: Undid precharge circuit with diode, resistor, and delay cap
    [peripherals.kicad_sch, power.kicad_sch]
2026-08-19 Checkpoint: Ready to spec rest of power stage tom
    [control.kicad_sch, drive.kicad_sch, power.kicad_sch]
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2026-08-25 Fixed annotations and H-labels
    [control.kicad_sch, drive.kicad_sch, esc.kicad_sch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]
2026-08-25 Update shunt resistors and resolve ERC errors
    [control.kicad_sch, drive.kicad_sch, peripherals.kicad_sch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]
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2026-08-31 Clear PCB-add errors
    [control.kicad_sch, drive.kicad_sch, esc.kicad_pcb]
2026-08-31 Add drive sheet components and remove redundant components
    [control.kicad_sch, esc.kicad_pcb, peripherals.kicad_sch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]
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2026-09-01 Place next tier of components after critical ones
    [control.kicad_sch, esc.kicad_pcb, peripherals.kicad_sch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]
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2026-09-02 Finish most of the layout, just the power stuff next!
    [esc.kicad_pcb, peripherals.kicad_sch]
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2026-09-05 Update board stackup front/back copper widths for 2 oz
    [esc.kicad_pcb]
2026-09-05 Fill in pours for GNDs (multiple) and VM. Soon is other VM_in-related nets and phase nodes!
    [esc.kicad_pcb]
2026-09-05 Add LCSC field, update diode values/datasheets, crystal part
    [control.kicad_sch, esc.csv, peripherals.kicad_sch]
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2026-09-06 Spec everything with LCSC except for simple passives and header pins
    [control.kicad_sch, drive.kicad_sch, esc.csv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]
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2026-09-06 Reclear ERC errors and resolve new PCB footprints after LCSC parts shift
    [control.kicad_sch, drive.kicad_sch, esc.csv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]
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2026-09-07 Place back copper pours and thermal vias throughout power section
    [esc.kicad_pcb]
2026-09-07 Resolve silkscreen and solder mask expansion errors before routing
    [esc.kicad_pcb]
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2026-09-09 Trace everything on power section except voltage sense resistors
    [esc.kicad_pcb]
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2026-09-10 Traces left are VM_SENSE, LEDs, CAN, and headers
    [esc.kicad_pcb]
2026-09-10 status LEDs and misc pins left to route
    [esc.kicad_pcb]
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2026-09-11 Add note about erroneous 3d model for VM connector
    [esc.kicad_pcb, peripherals.kicad_sch]
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2026-09-12 Make schem sheets page size match Ax format aspect ratio
    [drive.kicad_sch, esc.kicad_sch]
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2026-09-12 Plot schem and take screenshots of pcb and 3d model, then place in docs folder
    [esc.kicad_pcb]
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
